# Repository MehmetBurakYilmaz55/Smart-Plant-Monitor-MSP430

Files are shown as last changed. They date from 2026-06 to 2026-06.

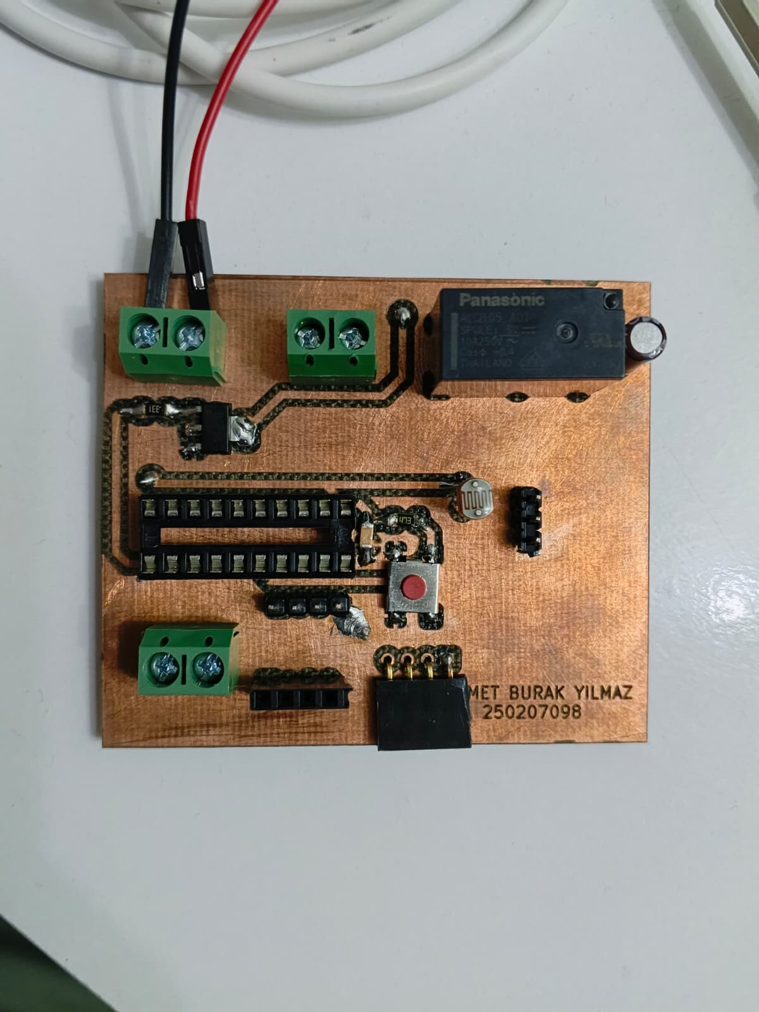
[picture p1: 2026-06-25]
Images/PCB_Front.jpeg

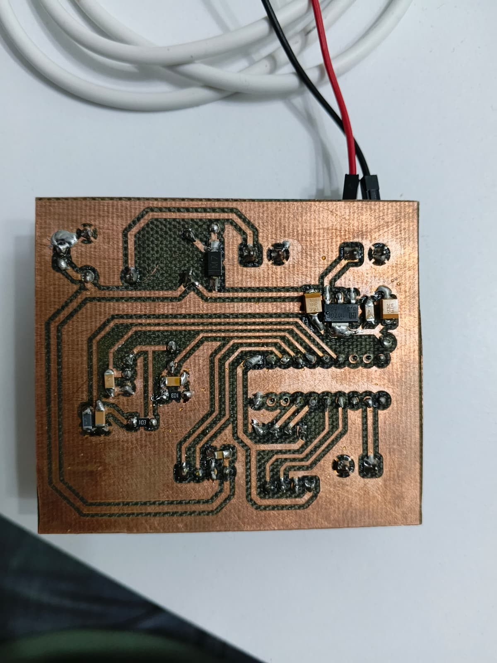
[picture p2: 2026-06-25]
Images/PCB_Back.jpeg

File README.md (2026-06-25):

# Akıllı Tarım Otomasyonu ve Gömülü Kontrol Sistemi (MSP430)

Bu proje, bir bitkinin çevresel ihtiyaçlarını (nem, sıcaklık, ışık) sürekli olarak analiz edip gerekli fiziksel müdahaleleri (sulama, yapay aydınlatma) otonom olarak gerçekleştiren donanım merkezli bir gömülü sistem projesidir. 

Projenin temel amacı, piyasadaki hazır sensör ve güç modülleri (breakout board) kullanım alışkanlıklarını bir kenara bırakarak; voltaj regülasyonundan güç anahtarlamaya kadar tüm elektriksel altyapının özel tasarlanmış **çift taraflı bir PCB** üzerinde komponent seviyesinde (component-level) birleştirilmesidir. Yazılım mimarisinde ise hiçbir soyutlama kütüphanesi (HAL veya standart kütüphane) kullanılmamış, doğrudan mikrodenetleyici register'larına müdahale edilmiştir.

---

## 🛠️ Donanım Mimarisi ve Çift Taraflı PCB Tasarımı

Sistemin en güçlü yönü, elektriksel bütünlüğü ve kararlılığı maksimize etmek amacıyla baştan sona özel olarak tasarlanan donanım altyapısıdır. Piyasada sıkça tercih edilen hazır modüllerden (Bluetooth ve OLED ekran hariç) tamamen kaçınılmış, sistem donanım seviyesinde sıfırdan kurgulanmıştır.

* **Çift Taraflı (Double-Sided) Özelleştirilmiş PCB:** Sinyal yolları ve yüksek akım çeken güç hatları, elektromanyetik girişimi (EMI) minimize edecek şekilde iki katmanlı olarak yönlendirilmiştir.
* **Tümleşik Voltaj Regülasyonu:** Harici bir güç modülü kullanılmaksızın, giriş gerilimini mikrodenetleyicinin ve sensörlerin ihtiyaç duyduğu kararlı 3.3V seviyesine düşüren lineer regülatör devresi doğrudan PCB üzerine gömülmüştür.
* **Komponent Seviyesinde Tasarım:** Hazır röle veya sensör kartları kullanılmamıştır. Su pompasını süren rölenin transistör tabanlı sürücü devresi (demeraj ve ters EMK korumaları dahil) ile sensör okuma hatlarının sinyal koşullandırma devreleri PCB üzerinde bağımsız komponentlerle dizayn edilmiştir.
* **Fiziksel Dayanım:** Ortam şartlarına ve elektromekanik titreşimlere karşı dirençli bir endüstriyel prototip elde edilmiştir.

---

## 💻 Yazılım Mimarisi (Bare-Metal)

Sistemin yazılımı, MSP430G2553 mikrodenetleyicisinin tüm kaynaklarını %100 kontrol edebilmek amacıyla tamamen **"Bare-Metal"** (kütüphanesiz) olarak C dilinde geliştirilmiştir.

* **Register-Level Programlama:** I2C, UART, ADC ve Timer donanımları hazır kütüphanelerle değil, doğrudan işlemci kaydedicileri (register) üzerinden bayt bayt yapılandırılmıştır.
* **Özel I2C ve OLED Sürücüsü:** SSD1306 OLED ekranı kontrol etmek için donanımsal I2C protokolü ve 5x8 ASCII font matrisi sıfırdan yazılarak sisteme entegre edilmiştir.
* **Donanımsal PWM Üretimi:** İşlemciyi döngüsel gecikmelerle (delay) yormamak adına, Timer_A modülü "Reset/Set" modunda (OUTMOD_7) çalıştırılarak pürüzsüz ve işlemciden bağımsız bir PWM sinyali elde edilmiştir.
* **Dinamik Sağlık Algoritması:** Sensörlerden alınan ham ADC verileri, lineer azalan ölçeklendirme matematiksel modeli ile işlenerek bitkinin anlık durumunu gösteren dinamik bir "Büyüme Kalitesi Puanına" dönüştürülür.
* **Histerezis Kontrolü:** Röle tetiklemelerinde sistemin kararsızlığa düşmesini (chatter effect) engellemek için yazılımsal ölü bölgeler (dead-zones) oluşturulmuştur.

---

## ⚙️ Temel Özellikler ve Otonom Fonksiyonlar

* **Akıllı Sulama:** Toprak nemi belirlenen kritik eşiğin altına düştüğünde su pompası devreye girer, ideal neme ulaşıldığında histerezis bandı sayesinde güvenli bir şekilde kapanır.
* **Ters Orantılı Aydınlatma:** Ortamdaki ışık (LDR) seviyesi düştükçe, PWM kontrollü yapay aydınlatma modülü otomatik olarak parlaklığını artırır.
* **Gerçek Zamanlı Telemetri:** Tüm sensör verileri, hesaplanan kalite puanı ve röle durumları Bluetooth (UART) üzerinden kablosuz olarak aktarılır.
* **Lokal Arayüz:** İşlenen veriler ve puan durumu, cihaz üzerindeki OLED ekranda anlık olarak görüntülenir.

---

## 🚀 Kullanılan Teknolojiler ve Bileşenler

* **Mikrodenetleyici:** Texas Instruments MSP430G2553
* **Sensör Ağı:** NTC (Sıcaklık), Analog Toprak Nemi Sensörü, LDR (Ortam Işığı)
* **Aktüatörler:** 5V Su Pompası (Transistör sürücülü röle ile kontrol edilir), LED Aydınlatma (Timer_A PWM destekli)
* **Haberleşme:** HC-05 / UART Bluetooth Modülü (Sadece modül olarak kullanılmıştır)
* **Görüntüleme:** 0.96" SSD1306 OLED (I2C) (Sadece modül olarak kullanılmıştır)
* **Geliştirme Ortamı:** Code Composer Studio (CCS)
* **PCB Tasarım:** KiCad

---

## 📂 Dosya ve Klasör Yapısı

Projenin donanım tasarımı, üretim çıktıları ve yazılım kaynak kodları modüler bir yapıda organize edilmiştir:

* **`C/`**: Sistemin beyni olan yazılımın bulunduğu dizindir. Herhangi bir hazır kütüphane kullanılmadan doğrudan register seviyesinde yazılmış Bare-Metal C kaynak kodlarını içerir.
* **`Docs/`**: Donanım tasarımının mutfağıdır. Devrenin **KiCad** üzerinde sıfırdan çizilmiş elektronik şematiklerini, çift taraflı PCB yerleşim (layout) planlarını ve lazer kazıma yöntemiyle üretime hazır hale getirilmiş ön/arka bakır (Cu) yüzey PDF çıktılarını barındırır.
* **`Images/`**: Teorik tasarımın fiziksel bir ürüne dönüşme serüvenini belgeler. Lazer kazıma makinesindeki üretim aşamalarından, montajı ve lehimlemesi bitmiş çift taraflı kartın detaylı fotoğraflarına kadar projenin donanımsal kalitesini gösteren görsel dökümanları içerir.

---

## 👨‍💻 Geliştirici

**Mehmet Burak Yılmaz** 
Kocaeli Üniversitesi - Elektronik ve Haberleşme Mühendisliği

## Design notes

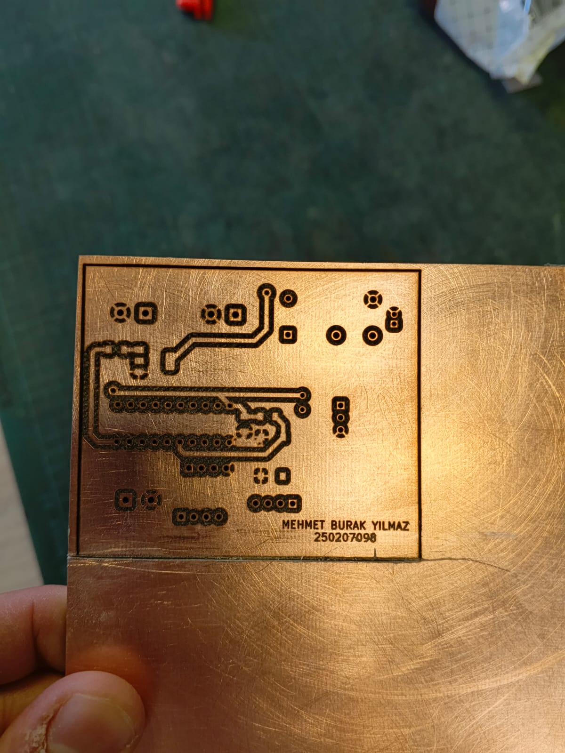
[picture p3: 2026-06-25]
Images/LaserCut.jpeg

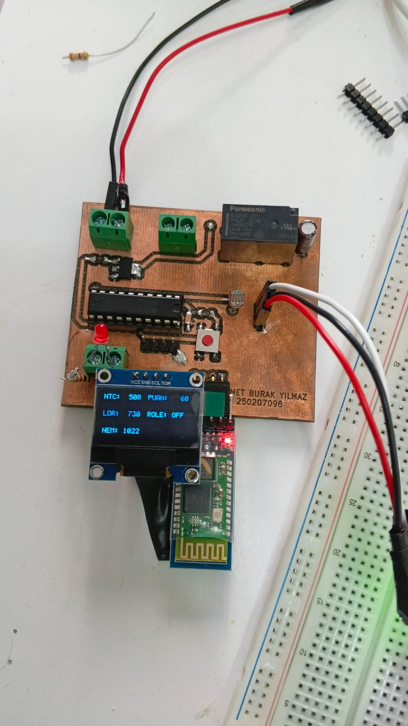
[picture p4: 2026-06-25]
Images/PCB.jpeg

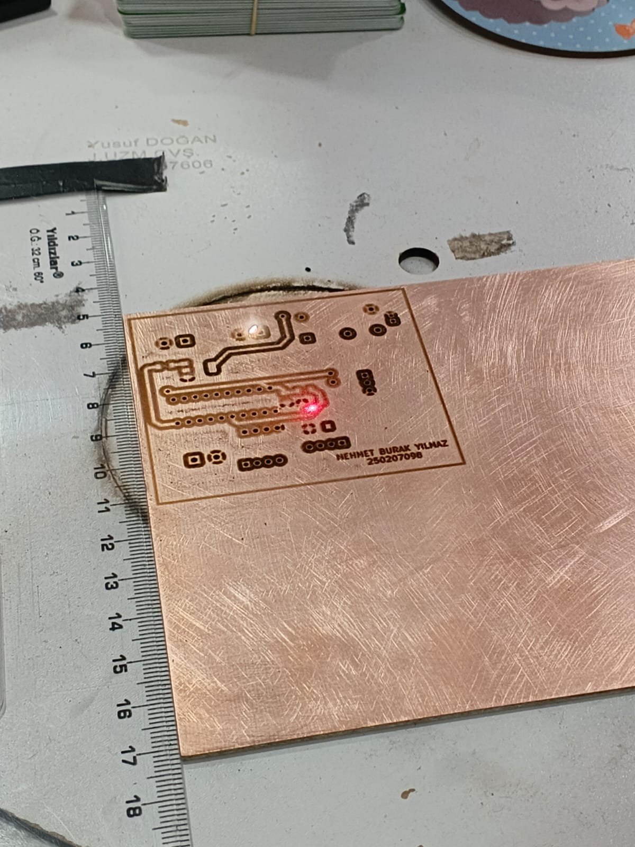
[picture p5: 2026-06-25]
Images/LaserCut1.jpeg

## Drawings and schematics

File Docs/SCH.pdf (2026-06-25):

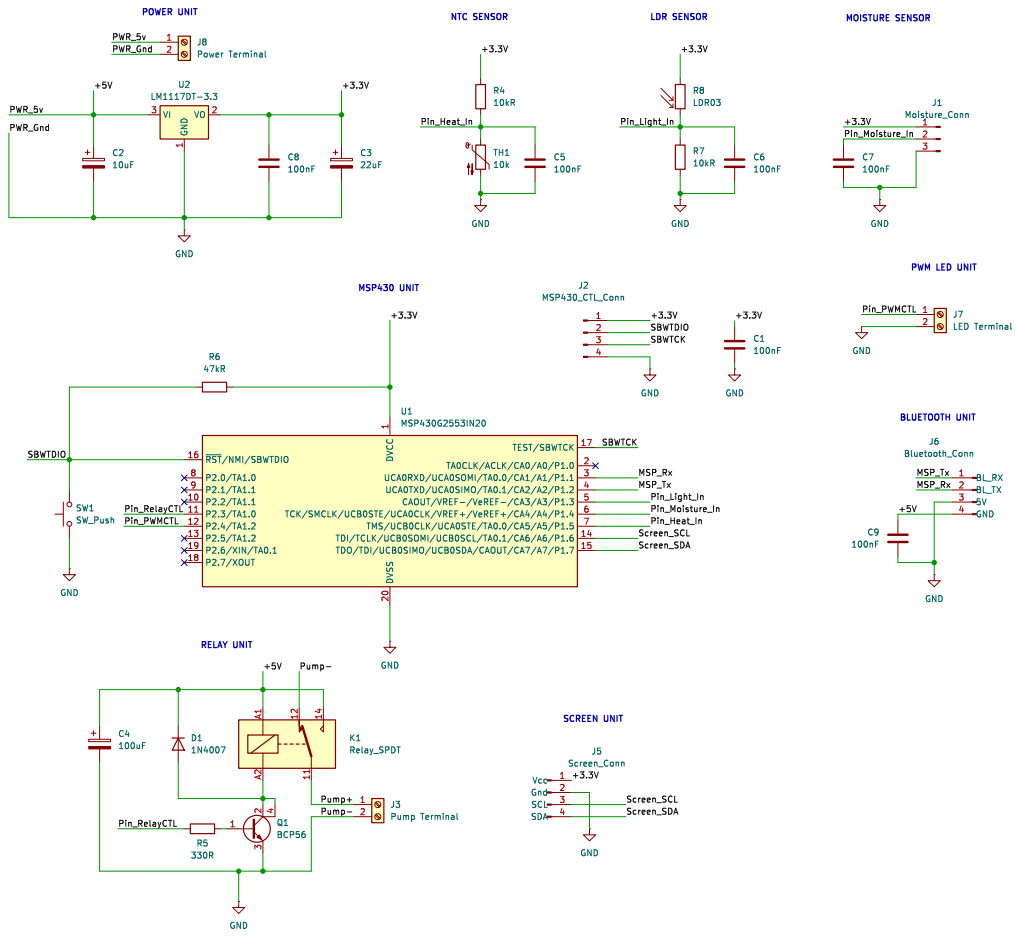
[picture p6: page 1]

LDR SENSOR MSP430 UNIT RELAY UNIT

1 DVSS 20 TEST/SBWTCK 17 TA0CLK/ACLK/CA0/A0/P1.0 2 UCA0RXD/UCA0SOMI/TA0.0/CA1/A1/P1.1 3 UCA0TXD/UCA0SIMO/TA0.1/CA2/A2/P1.2 4 CAOUT/VREF-/VeREF-/CA3/A3/P1.3 5 TCK/SMCLK/UCB0STE/UCA0CLK/VREF+/VeREF+/CA4/A4/P1.4 6 TMS/UCB0CLK/UCA0STE/TA0.0/CA5/A5/P1.5 7 TDI/TCLK/UCB0SOMI/UCB0SCL/TA0.1/CA6/A6/P1.6 14 TDO/TDI/UCB0SIMO/UCB0SDA/CAOUT/CA7/A7/P1.7 15 U1 MSP430G2553IN20

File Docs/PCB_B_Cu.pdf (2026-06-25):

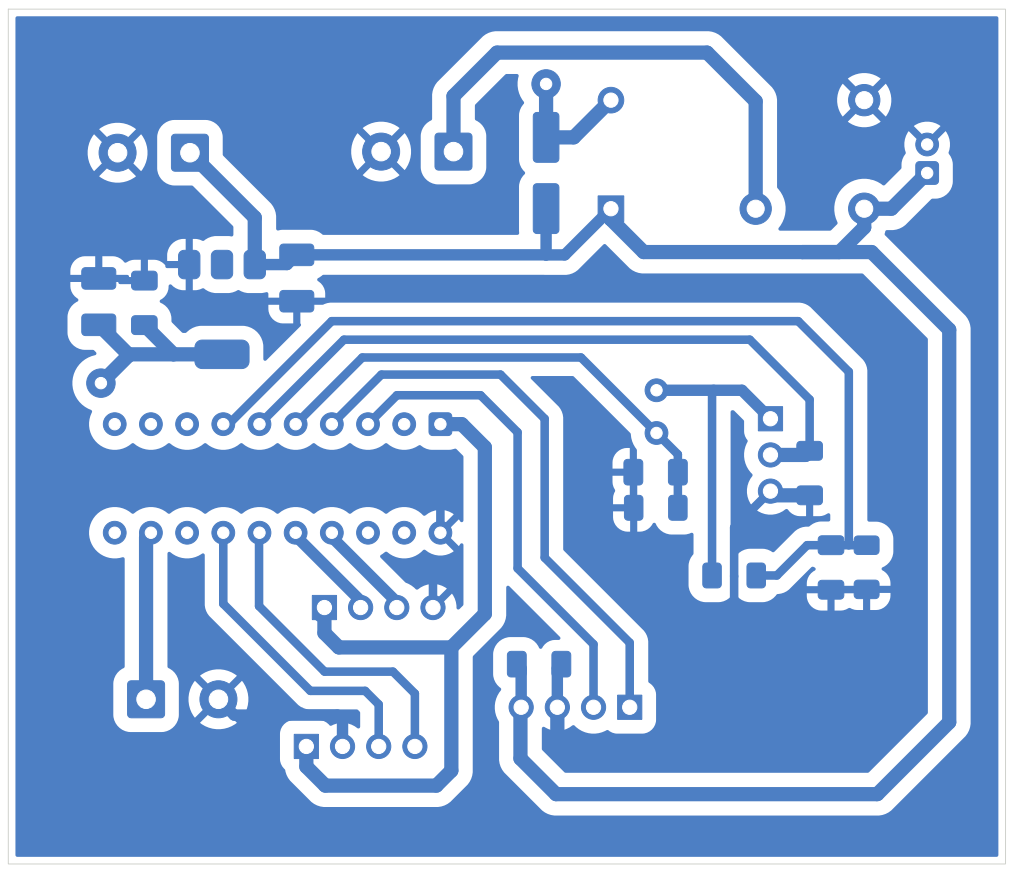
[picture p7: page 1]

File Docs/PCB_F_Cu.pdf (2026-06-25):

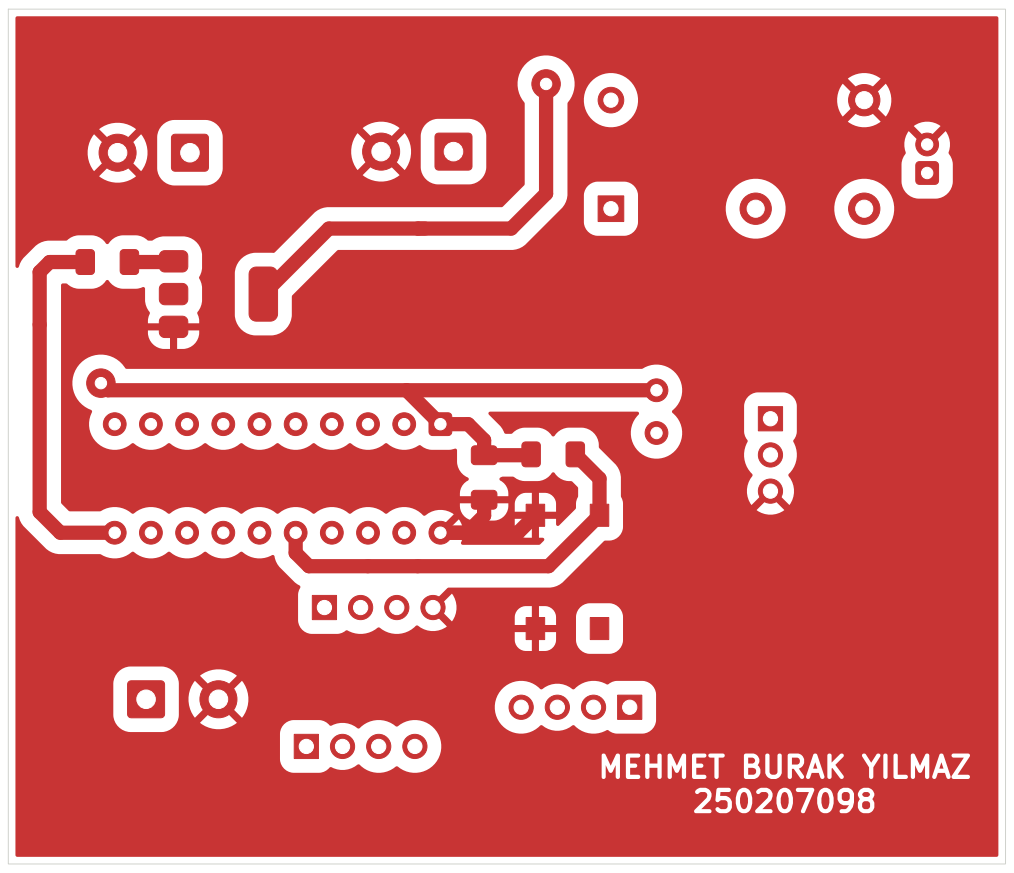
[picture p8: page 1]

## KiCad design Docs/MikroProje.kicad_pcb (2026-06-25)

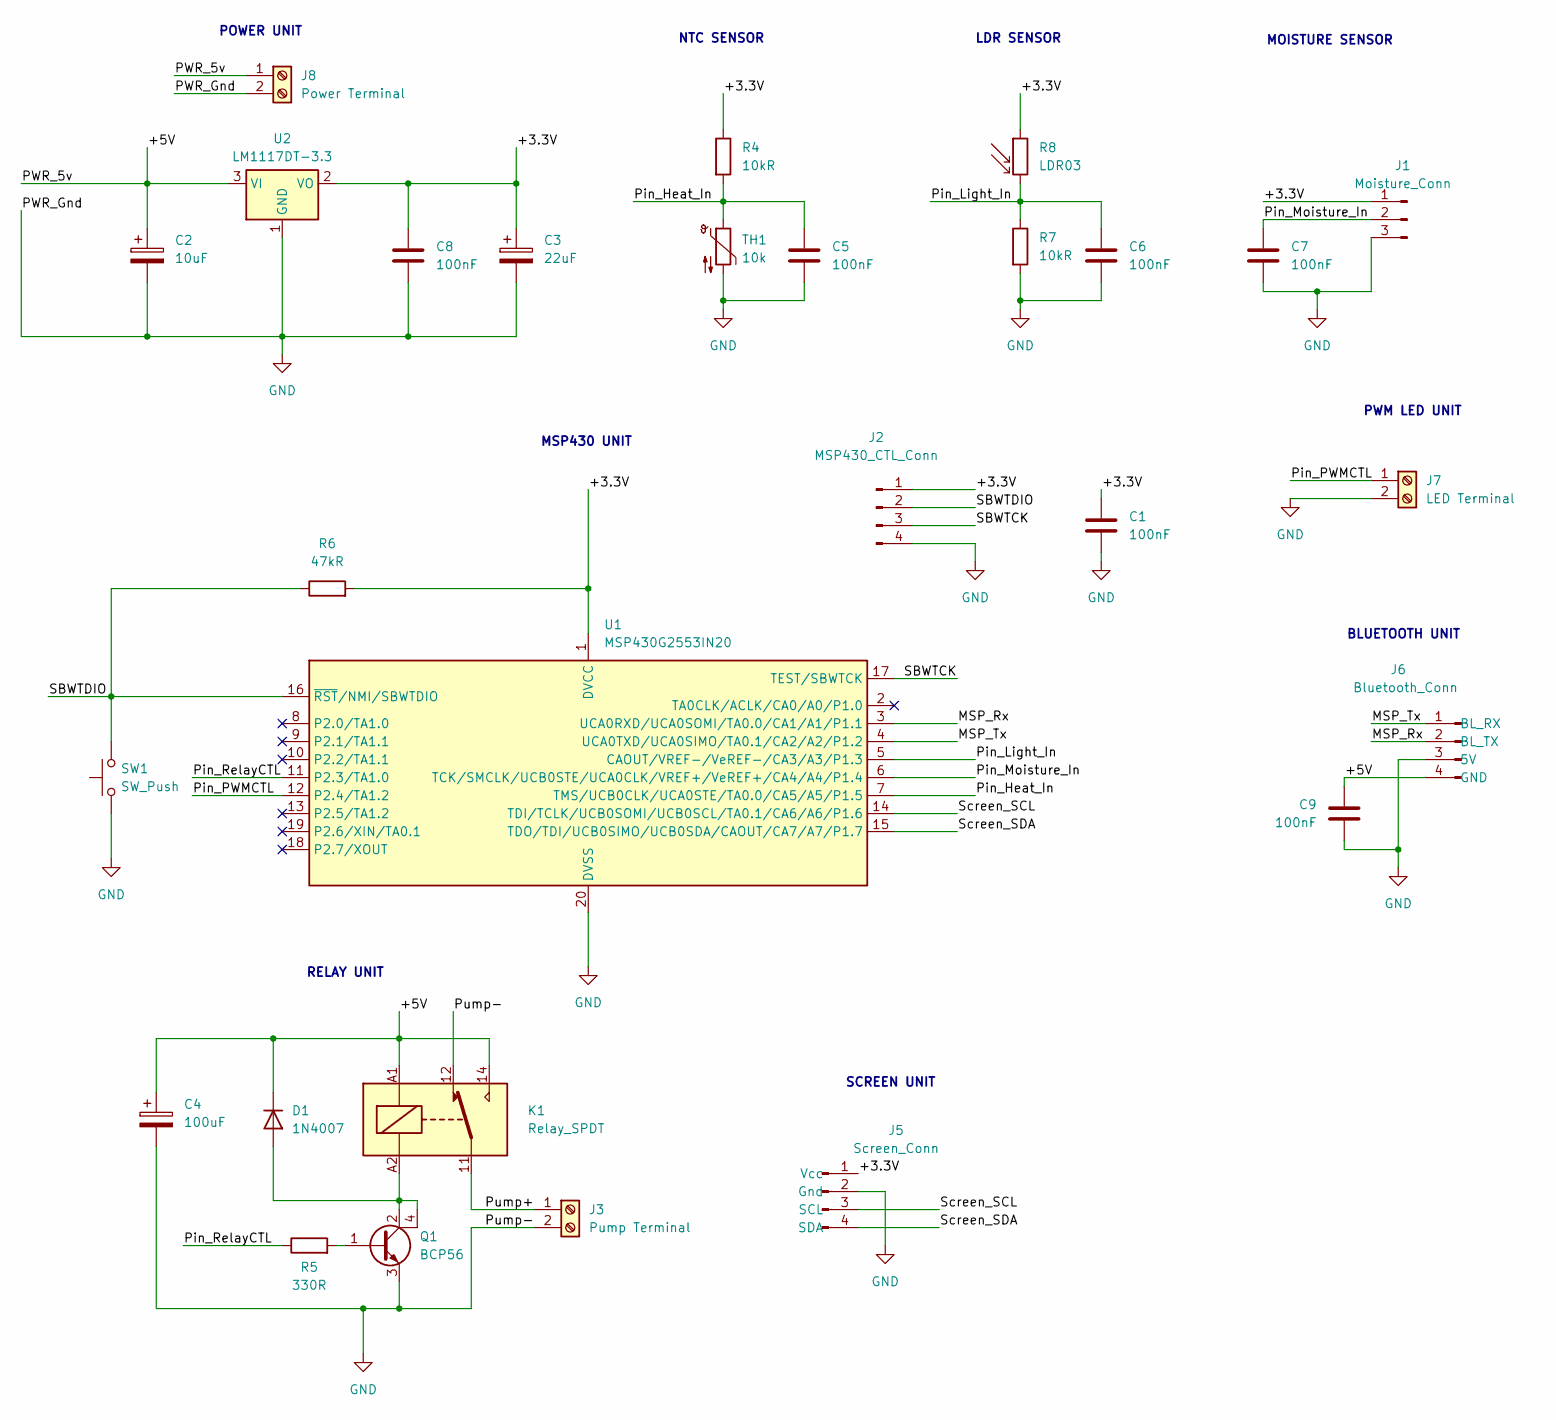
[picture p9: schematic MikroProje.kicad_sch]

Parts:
C1, C5, C6, C7, C8, C9: 100nF; C_1206_3216Metric_Pad1.33x1.80mm_HandSolder
C2: 10uF; CP_EIA-3528-21_Kemet-B_HandSolder
C3: 22uF; CP_EIA-3528-21_Kemet-B_HandSolder
C4: 100uF; CP_Radial_D5.0mm_P2.00mm
D1: 1N4007; D_SMA_Handsoldering
J1: Moisture_Conn; PinSocket_1x03_P2.54mm_Vertical
J2: MSP430_CTL_Conn; PinHeader_1x04_P2.54mm_Vertical
J3: Pump Terminal; TerminalBlock_Phoenix_MKDS-1,5-2-5.08_1x02_P5.08mm_Horizont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
J5: Screen_Conn; PinSocket_1x04_P2.54mm_Vertical
J6: Bluetooth_Conn; PinSocket_1x04_P2.54mm_Vertical
J7: LED Terminal; TerminalBlock_Phoenix_MKDS-1,5-2-5.08_1x02_P5.08mm_Horizont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
J8: Power Terminal; TerminalBlock_Phoenix_MKDS-1,5-2-5.08_1x02_P5.08mm_Horizont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
K1: Relay_SPDT; Relay_SPDT_Finder_32.21-x000
Q1: BCP56; SOT-223
R4, R7: 10kR; R_1206_3216Metric_Pad1.30x1.75mm_HandSolder
R5: 330R; R_1206_3216Metric_Pad1.30x1.75mm_HandSolder
R6: 47kR; R_1206_3216Metric_Pad1.30x1.75mm_HandSolder
R8: LDR03; R_LDR_5.0x4.1mm_P3mm_Vertical
SW1: SW_Push; SW_SPST_B3S-1000
TH1: 10k; R_1206_3216Metric_Pad1.30x1.75mm_HandSolder
U1: MSP430G2553IN20; DIP-20_W7.62mm
U2: LM1117DT-3.3; SOT-223-3_TabPin2

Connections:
/+3.3V: C1.1, C3.1, C8.1, J1.1, J2.1, J5.1 (Vcc), R4.1, R6.2, R8.1, U1.1 (DVCC), U2.2 (VO)
/+5V: C2.1, C4.1, C9.1, D1.1 (K), J6.4 (GND), J8.1, K1.14, K1.A1, U2.3 (VI)
/MSP_Rx: J6.2 (BL_TX), U1.3 (UCA0RXD/UCA0SOMI/TA0.0/CA1/A1/P1.1)
/MSP_Tx: J6.1 (BL_RX), U1.4 (UCA0TXD/UCA0SIMO/TA0.1/CA2/A2/P1.2)
/Pin_Heat_In: C5.1, R4.2, TH1.1, U1.7 (TMS/UCB0CLK/UCA0STE/TA0.0/CA5/A5/P1.5)
/Pin_Light_In: C6.1, R7.1, R8.2, U1.5 (CAOUT/VREF-/VeREF-/CA3/A3/P1.3)
/Pin_Moisture_In: C7.1, J1.2, U1.6 (TCK/SMCLK/UCB0STE/UCA0CLK/VREF+/VeREF+/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)
/Pin_PWMCTL: J7.1, U1.12 (P2.4/TA1.2)
/Pin_RelayCTL: R5.1, U1.11 (P2.3/TA1.0)
/Pump+: J3.1, K1.11
/SBWTCK: J2.3, U1.17 (TEST/SBWTCK)
/SBWTDIO: J2.2, R6.1, SW1.2, U1.16 (~RST/NMI/SBWTDIO)
/Screen_SCL: J5.3 (SCL), U1.14 (TDI/TCLK/UCB0SOMI/UCB0SCL/TA0.1/CA6/A6/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)
/Screen_SDA: J5.4 (SDA), U1.15 (TDO/TDI/UCB0SIMO/UCB0SDA/CAOUT/CA7/A7/P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)
GND: C1.2, C2.2, C3.2, C4.2, C5.2, C6.2, C7.2, C8.2, C9.2, J1.3, J2.4, J3.2, J5.2 (Gnd), J6.3 (5V), J7.2, J8.2, K1.12, Q1.3 (E), R7.2, SW1.1, TH1.2, U1.20 (DVSS), U2.1 (GND)
unnamed: D1.2 (A), K1.A2, Q1.2 (C), Q1.4 (C)
unnamed: Q1.1 (B), R5.2

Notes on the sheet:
BLUETOOTH UNIT
MOISTURE SENSOR
NTC SENSOR
MSP430 UNIT
LDR SENSOR
SCREEN UNIT
POWER UNIT
RELAY UNIT
PWM LED UNIT

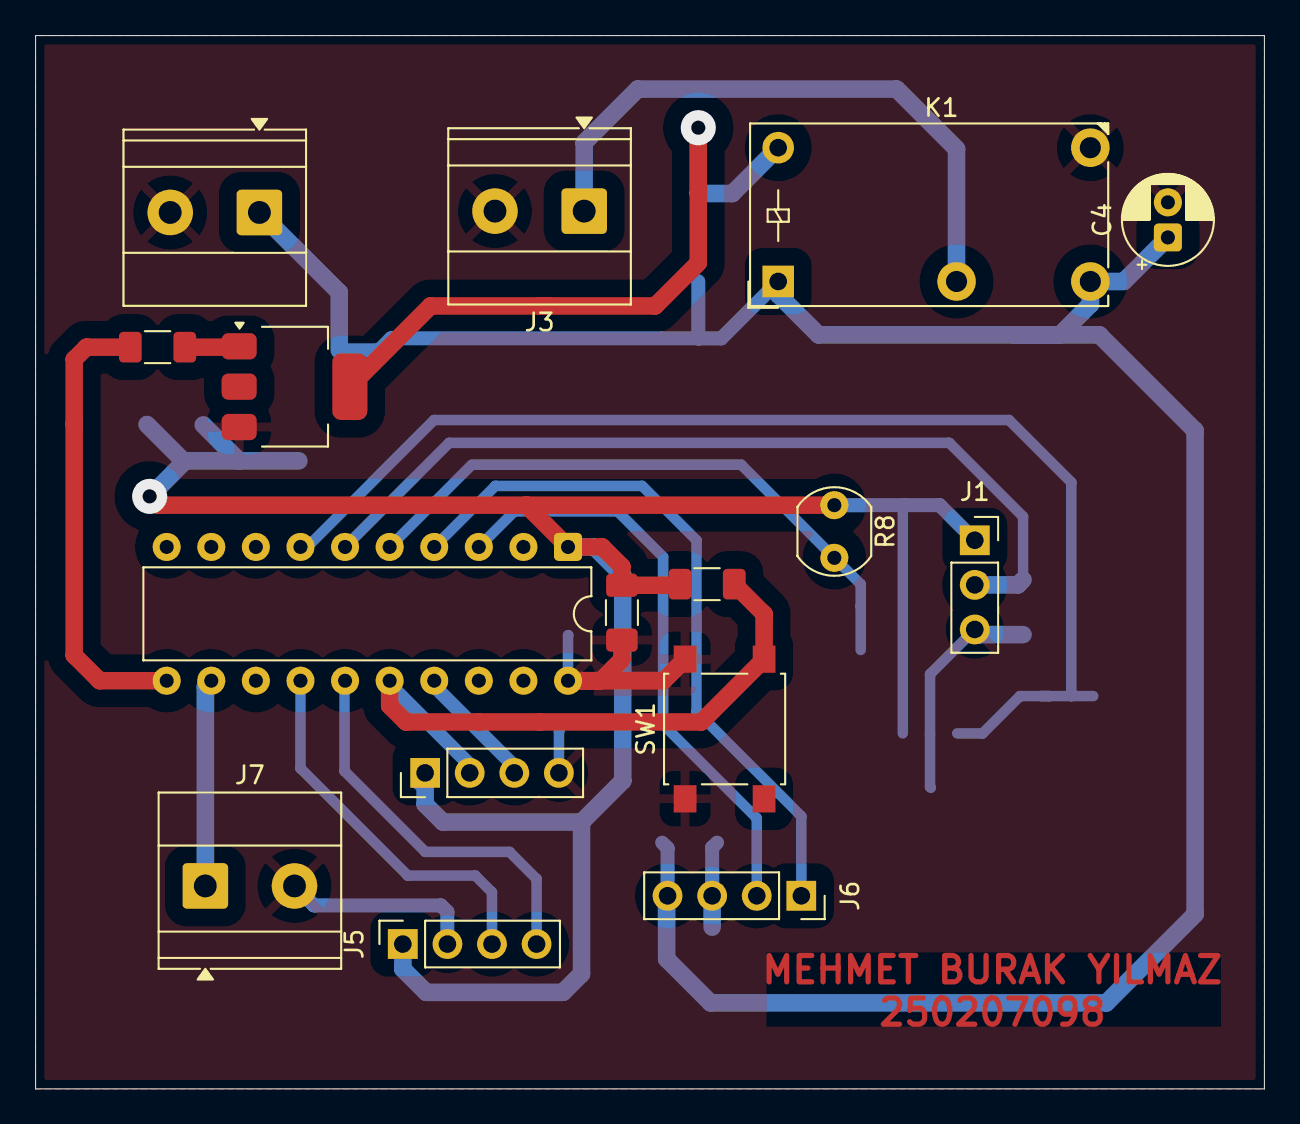
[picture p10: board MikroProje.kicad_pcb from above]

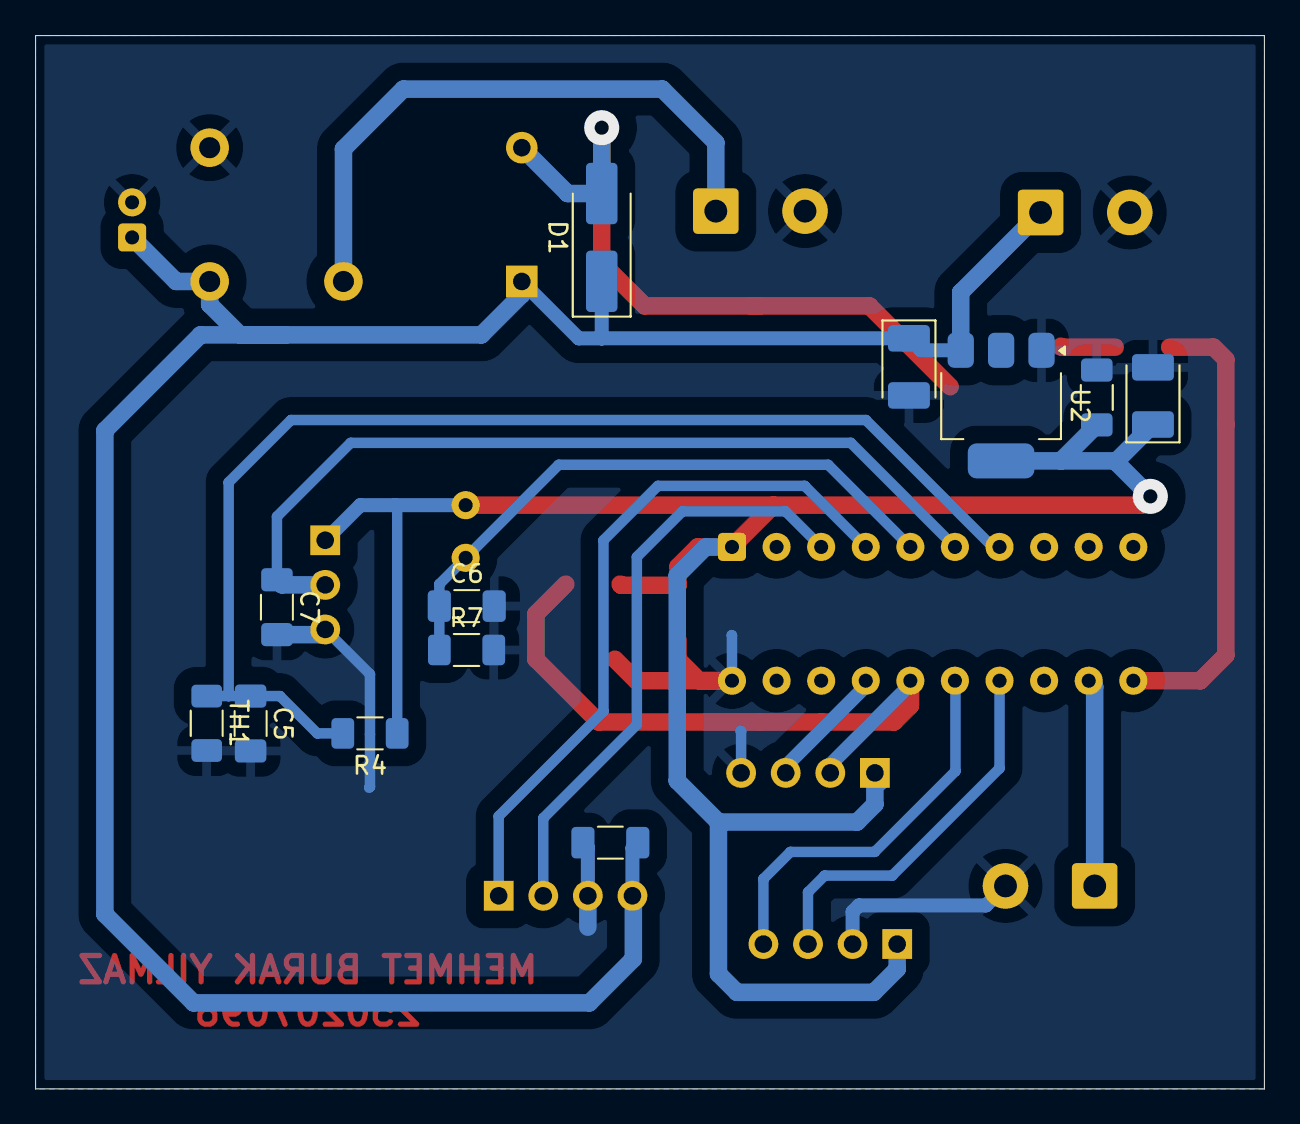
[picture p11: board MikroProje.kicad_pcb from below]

Board: 2 copper layers, 70.0 x 60.0 mm, 28 parts (12 on the bottom side), 17 nets.

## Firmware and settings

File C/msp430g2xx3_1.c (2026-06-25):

#include <msp430.h>

#define OLED_ADDR 0x3C 

const unsigned char font_karakterler[25][5] = {
    {0x3E, 0x51, 0x49, 0x45, 0x3E}, // 0
    {0x00, 0x42, 0x7F, 0x40, 0x00}, // 1
    {0x42, 0x61, 0x51, 0x49, 0x46}, // 2
    {0x21, 0x41, 0x45, 0x4B, 0x31}, // 3
    {0x18, 0x14, 0x12, 0x7F, 0x10}, // 4
    {0x27, 0x45, 0x45, 0x45, 0x39}, // 5
    {0x3C, 0x4A, 0x49, 0x49, 0x30}, // 6
    {0x01, 0x71, 0x09, 0x05, 0x03}, // 7
    {0x36, 0x49, 0x49, 0x49, 0x36}, // 8
    {0x06, 0x49, 0x49, 0x29, 0x1E}, // 9
    {0x00, 0x00, 0x00, 0x00, 0x00}, // 10: Boşluk
    {0x7F, 0x04, 0x08, 0x10, 0x7F}, // 11: 'N'
    {0x01, 0x01, 0x7F, 0x01, 0x01}, // 12: 'T'
    {0x3E, 0x41, 0x41, 0x41, 0x22}, // 13: 'C'
    {0x00, 0x36, 0x36, 0x00, 0x00}, // 14: ':' 
    {0x7F, 0x49, 0x49, 0x49, 0x41}, // 15: 'E'
    {0x7F, 0x02, 0x04, 0x02, 0x7F}, // 16: 'M'
    {0x7F, 0x40, 0x40, 0x40, 0x40}, // 17: 'L'
    {0x7F, 0x41, 0x41, 0x41, 0x3E}, // 18: 'D'
    {0x7F, 0x09, 0x19, 0x29, 0x46}, // 19: 'R'
    {0x3E, 0x41, 0x41, 0x41, 0x3E}, // 20: 'O' 
    {0x7F, 0x09, 0x09, 0x09, 0x01}, // 21: 'F' 
    {0x7F, 0x09, 0x09, 0x09, 0x06}, // 22: 'P' 
    {0x3F, 0x40, 0x40, 0x40, 0x3F}, // 23: 'U' 
    {0x7E, 0x11, 0x11, 0x11, 0x7E}  // 24: 'A' 
};

void UART_init(void) {
    P1SEL  |= BIT1 + BIT2;      
    P1SEL2 |= BIT1 + BIT2;      
    UCA0CTL1 |= UCSSEL_2;       
    UCA0BR0 = 104;              
    UCA0BR1 = 0;
    UCA0MCTL = UCBRS0;          
    UCA0CTL1 &= ~UCSWRST;       
}

void UART_Gonder_Metin(char *metin) {
    while (*metin) {
        while (!(IFG2 & UCA0TXIFG)); 
        UCA0TXBUF = *metin++;        
    }
}

void UART_Gonder_Sayi(int sayi) {
    char buffer[6];
    int i = 4;
    buffer[5] = '\0';
    if (sayi < 0) sayi = 0; 
    if (sayi == 0) { UART_Gonder_Metin("0"); return; }
    while (sayi > 0) {
        buffer[i--] = (sayi % 10) + '0';
        sayi /= 10;
    }
    UART_Gonder_Metin(&buffer[i + 1]);
}


void I2C_init(void) {
    P1SEL |= BIT6 + BIT7;
    P1SEL2 |= BIT6 + BIT7;
    UCB0CTL1 |= UCSWRST;
    UCB0CTL0 = UCMST + UCMODE_3 + UCSYNC;
    UCB0CTL1 = UCSSEL_2 + UCSWRST;
    UCB0BR0 = 10;
    UCB0BR1 = 0;
    UCB0I2CSA = OLED_ADDR;
    UCB0CTL1 &= ~UCSWRST;
}

void I2C_write(unsigned char control, unsigned char data) {
    while (UCB0CTL1 & UCTXSTP); 
    UCB0CTL1 |= UCTR + UCTXSTT;
    while (!(IFG2 & UCB0TXIFG));
    UCB0TXBUF = control;
    while (!(IFG2 & UCB0TXIFG));
    UCB0TXBUF = data;
    while (!(IFG2 & UCB0TXIFG));
    UCB0CTL1 |= UCTXSTP; 
}

void OLED_command(unsigned char cmd) { I2C_write(0x00, cmd); }
void OLED_data(unsigned char data)   { I2C_write(0x40, data); }

void OLED_init(void) {
    OLED_command(0xAE); OLED_command(0xD5); OLED_command(0x80); 
    OLED_command(0xA8); OLED_command(0x3F); OLED_command(0xD3); 
    OLED_command(0x00); OLED_command(0x40); OLED_command(0x8D); 
    OLED_command(0x14); OLED_command(0x20); OLED_command(0x00); 
    OLED_command(0xA1); OLED_command(0xC8); OLED_command(0xDA); 
    OLED_command(0x12); OLED_command(0x81); OLED_command(0xCF); 
    OLED_command(0xD9); OLED_command(0xF1); OLED_command(0xDB); 
    OLED_command(0x40); OLED_command(0xA4); OLED_command(0xA6); 
    OLED_command(0xAF); 
}

void OLED_clear(void) {
    int page, col;
    for (page = 0; page < 8; page++) {
        OLED_command(0xB0 + page);
        OLED_command(0x00);
        OLED_command(0x10);
        for (col = 0; col < 128; col++) {
            OLED_data(0x00);
        }
    }
}

void OLED_Imlec(unsigned char satir, unsigned char sutun) {
    OLED_command(0xB0 + satir);           
    OLED_command(sutun & 0x0F);           
    OLED_command(0x10 | (sutun >> 4));    
}

void OLED_Karakter_Yaz(unsigned char indeks) {
    unsigned char i;
    for (i = 0; i < 5; i++) {
        OLED_data(font_karakterler[indeks][i]); 
    }
    OLED_data(0x00); 
}

void OLED_Sayi_Yaz(unsigned int sayi) {
    if(sayi < 1000) OLED_Karakter_Yaz(10); 
    else OLED_Karakter_Yaz(sayi / 1000);       
    if(sayi < 100) OLED_Karakter_Yaz(10);
    else OLED_Karakter_Yaz((sayi / 100) % 10); 
    if(sayi < 10) OLED_Karakter_Yaz(10);
    else OLED_Karakter_Yaz((sayi / 10) % 10);  
    OLED_Karakter_Yaz(sayi % 10);              
}

unsigned int ADC_Oku(unsigned char kanal) {
    ADC10CTL0 &= ~ENC; 
    if (kanal == 3) ADC10CTL1 = INCH_3; 
    if (kanal == 4) ADC10CTL1 = INCH_4; 
    if (kanal == 5) ADC10CTL1 = INCH_5; 
    ADC10CTL0 |= ENC + ADC10SC; 
    while (!(ADC10CTL0 & ADC10IFG)); 
    ADC10CTL0 &= ~ADC10IFG;          
    return ADC10MEM; 
}


int main(void) {
    WDTCTL = WDTPW + WDTHOLD;

    DCOCTL = 0;
    BCSCTL1 = CALBC1_1MHZ;
    DCOCTL = CALDCO_1MHZ;

    P2DIR |= BIT3;    
    P2OUT &= ~BIT3;   

    P2DIR |= BIT4;        
    P2SEL |= BIT4;        
    TA1CCR0 = 1000;       
    TA1CCTL2 = OUTMOD_7;  
    TA1CCR2 = 0;          
    TA1CTL = TASSEL_2 + MC_1; 

    
    UART_init();
    I2C_init();
    __delay_cycles(100000);
    OLED_init();
    OLED_clear();

    ADC10AE0 |= BIT3 + BIT4 + BIT5; 
    ADC10CTL0 = ADC10SHT_3 + ADC10ON; 

    while(1) {
        unsigned int ldr_deger = ADC_Oku(3);
        unsigned int nem_deger = ADC_Oku(4); 
        unsigned int ntc_deger = ADC_Oku(5);

        int nem_fark = nem_deger - 500;
        if (nem_fark < 0) nem_fark = -nem_fark; 
        int nem_puan = 40 - ((nem_fark * 40) / 500);
        if (nem_puan < 0) nem_puan = 0;

        int ntc_fark = ntc_deger - 500;
        if (ntc_fark < 0) ntc_fark = -ntc_fark; 
        int ntc_puan = 40 - ((ntc_fark * 40) / 500);
        if (ntc_puan < 0) ntc_puan = 0;

        int ldr_puan = (ldr_deger * 20) / 1000;
        if (ldr_puan > 20) ldr_puan = 20;

        int kalite_puani = nem_puan + ntc_puan + ldr_puan;
        if (kalite_puani > 100) kalite_puani = 100;
        if (kalite_puani < 0) kalite_puani = 0;

        int pwm_hedef = 1000 - ldr_deger;
        if (pwm_hedef < 0) pwm_hedef = 0;
        if (pwm_hedef > 1000) pwm_hedef = 1000;
        TA1CCR2 = pwm_hedef; 

        if (nem_deger > 700) {
            P2OUT |= BIT3;  
        } else if (nem_deger < 400) {
            P2OUT &= ~BIT3; 
        }

        UART_Gonder_Metin("ISIK: ");  UART_Gonder_Sayi(ldr_deger);
        UART_Gonder_Metin(" | NEM: "); UART_Gonder_Sayi(nem_deger);
        UART_Gonder_Metin(" | ISI: "); UART_Gonder_Sayi(ntc_deger);
        UART_Gonder_Metin(" | PUAN: "); UART_Gonder_Sayi(kalite_puani);

        if (P2OUT & BIT3){

             UART_Gonder_Metin(" | ROLE: ON \r\n");
        }
        else{

               UART_Gonder_Metin(" | ROLE: OFF\r\n");
        }       

        OLED_Imlec(0, 0); // Satır 0
        OLED_Karakter_Yaz(11); OLED_Karakter_Yaz(12); OLED_Karakter_Yaz(13); OLED_Karakter_Yaz(14); // NTC:
        OLED_Karakter_Yaz(10); OLED_Sayi_Yaz(ntc_deger); 

        OLED_Imlec(3, 0); // Satır 3
        OLED_Karakter_Yaz(17); OLED_Karakter_Yaz(18); OLED_Karakter_Yaz(19); OLED_Karakter_Yaz(14); // LDR:
        OLED_Karakter_Yaz(10); OLED_Sayi_Yaz(ldr_deger); 

        OLED_Imlec(6, 0); // Satır 6
        OLED_Karakter_Yaz(11); OLED_Karakter_Yaz(15); OLED_Karakter_Yaz(16); OLED_Karakter_Yaz(14); // NEM:
        OLED_Karakter_Yaz(10); OLED_Sayi_Yaz(nem_deger); 

        OLED_Imlec(0, 64); 
        OLED_Karakter_Yaz(22); OLED_Karakter_Yaz(23); OLED_Karakter_Yaz(24); OLED_Karakter_Yaz(11); // PUAN
        OLED_Karakter_Yaz(14); OLED_Karakter_Yaz(10); OLED_Sayi_Yaz(kalite_puani);

        OLED_Imlec(3, 64); 
        if (P2OUT & BIT3) {
            OLED_Karakter_Yaz(19); OLED_Karakter_Yaz(20); OLED_Karakter_Yaz(17); OLED_Karakter_Yaz(15); // ROLE
            OLED_Karakter_Yaz(14); OLED_Karakter_Yaz(10); 
            OLED_Karakter_Yaz(20); OLED_Karakter_Yaz(11); OLED_Karakter_Yaz(10); // ON(Boşluk)
        } else {
            OLED_Karakter_Yaz(19); OLED_Karakter_Yaz(20); OLED_Karakter_Yaz(17); OLED_Karakter_Yaz(15); // ROLE
            OLED_Karakter_Yaz(14); OLED_Karakter_Yaz(10); 
            OLED_Karakter_Yaz(20); OLED_Karakter_Yaz(21); OLED_Karakter_Yaz(21); // OFF
        }

        __delay_cycles(300000); 
    }
}
